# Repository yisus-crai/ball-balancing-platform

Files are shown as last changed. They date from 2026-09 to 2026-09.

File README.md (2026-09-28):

# 2-DOF Ball-Balancing Platform

<p align="center">
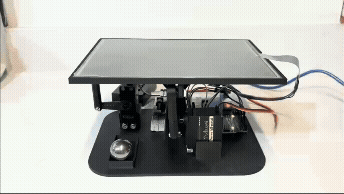
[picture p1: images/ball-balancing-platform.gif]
Ball-balancing demo
  
</p>

## About
A two-degree-of-freedom ball-balancing platform designed, built, and programmed as a personal engineering project.

The platform uses a resistive touchscreen to measure the ball position and two servomotors to tilt the surface. Two independent closed-loop PID controllers stabilize the ball near the center of the platform. 

## Project Goals

- Apply classical control concepts to a physical system.
- Design and manufacture the mechanical structure.
- Implement real-time position measurement and filtering.
- Develop and tune a closed-loop controller on an Arduino.
- Explore future control approaches such as state-space control and Kalman filtering.

## Hardware & Components

- Arduino UNO
- 2 × MG995 servo motors
- 8 inch 4-wire resistive touchscreen
- External 5 V power supply for the servo motors
- Custom 2-DOF mechanical platform (designed via CAD + 3D-printed)
- 25 mm diameter stainless-steel ball

## Design

The platform was designed as a two-degree-of-freedom mechanism capable of tilting independently around the X and Y axes.

The mechanical structure consists of:

- A fixed base.
- A moving platform that supports the resistive touchscreen.
- Two MG995 servomotors, one for each axis.
- Mechanical linkages that convert servo rotation into platform tilt.
- 3D-Printed structural components.
- A ball used as the controlled object.

All structural components were designed in CAD using Autodesk Fusion and manufactured by 3D printing in PLA. The design was iterated to achieve adequate rigidity, servo clearance, and a suitable range of platform motion. 

<p align="center">
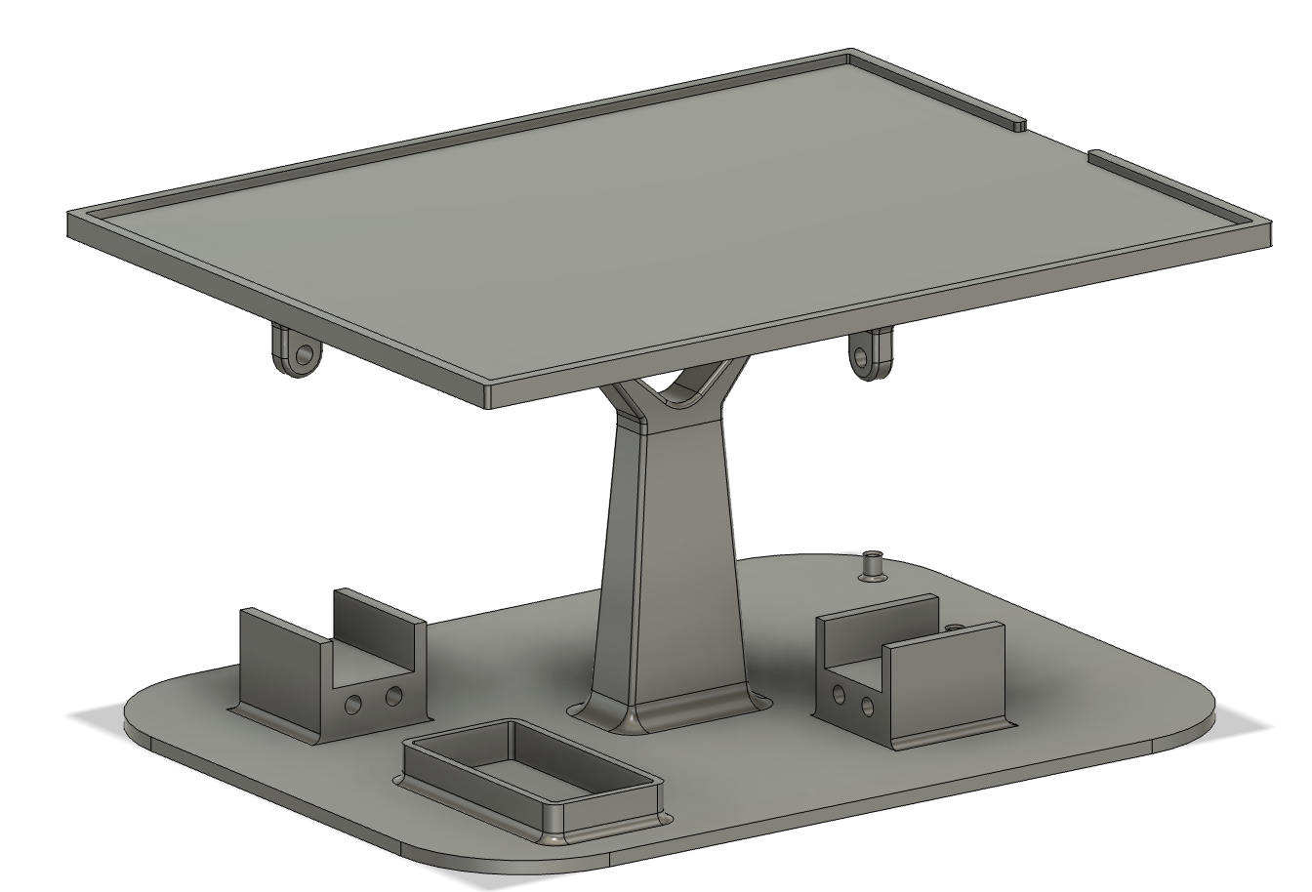
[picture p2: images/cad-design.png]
cad design assembled
  
</p>

The final assembly uses bolts and nuts to join the printed parts, servomotors and base structure. The touchscreen is fitted into the tilting platform with minimal clearance to prevent displacement, avoiding the use of bolts that could apply unwanted stress to the touchscreen.

The platform tilt was limited to approximately ±10° on each axis. This constraint reduces excessive ball acceleration, keeps the ball in contact with the touchscreen, and prevents mechanical interference.

##  Software Architecture

The Arduino firmware is organized around a repeated sensing, filtering, control, and actuation loop.

1. **Position measurement**  
   The Arduino reads the X and Y coordinates from a 4-wire resistive touchscreen.

2. **Signal filtering**  
   A median filter rejects outliers from the touchscreen measurements. An Exponential Moving Average (EMA) then smooths the remaining noise.

3. **Control computation**  
   Independent PID controllers calculate the required correction for the X and Y axes. Each controller stores its own gains, filtered position, previous error, integral state, derivative state, and output limits.

4. **Actuation**  
   The controller outputs are converted into servo commands relative to the mechanical neutral position.

5. **Safety handling**  
   If the ball is not detected for a defined period, both servos return to the neutral position and the controller states are reset.

Main Code Components:

- `AxisControl`: Stores the state and parameters associated with one control axis.
- `median()`: Calculates the median of recent touchscreen measurements.
- `ema()`: Applies the exponential moving average filter.
- `PID()`: Calculates the control output for an axis.
- `restartAxis()`: Resets controller states after ball detection is lost.

## Troubleshooting

Several practical issues arose during development and were addressed as follows:

- **Excessive serial output slowed down the control loop.**  
  Frequent `Serial.print()` calls introduced delays and degraded the controller performance.  
  - **Solution:** Reduce or disable serial output during normal operation. Use `Serial.print()` only for debugging.

- **Inadequate servo power supply reduced actuator performance.**  
  Powering the servos from the Arduino 5 V pin resulted in slow and unreliable motion.  
  - **Solution:** Power the servos from a suitable external 5 V supply and connect its ground to the Arduino GND.

- **Derivative kick occurred when the ball was first detected.**  
  The derivative term produced a large output because the previous error was not initialized.  
  - **Solution:** Initialize the controller state after obtaining the first valid position measurements, then enable derivative control.

- **Filtering introduced a trade-off between noise reduction and response delay.**  
  Excessive filtering made the position estimate smoother but delayed the control action.  
  - **Solution:** Tune the median-filter window, EMA coefficient, and sampling interval to balance noise rejection and responsiveness.

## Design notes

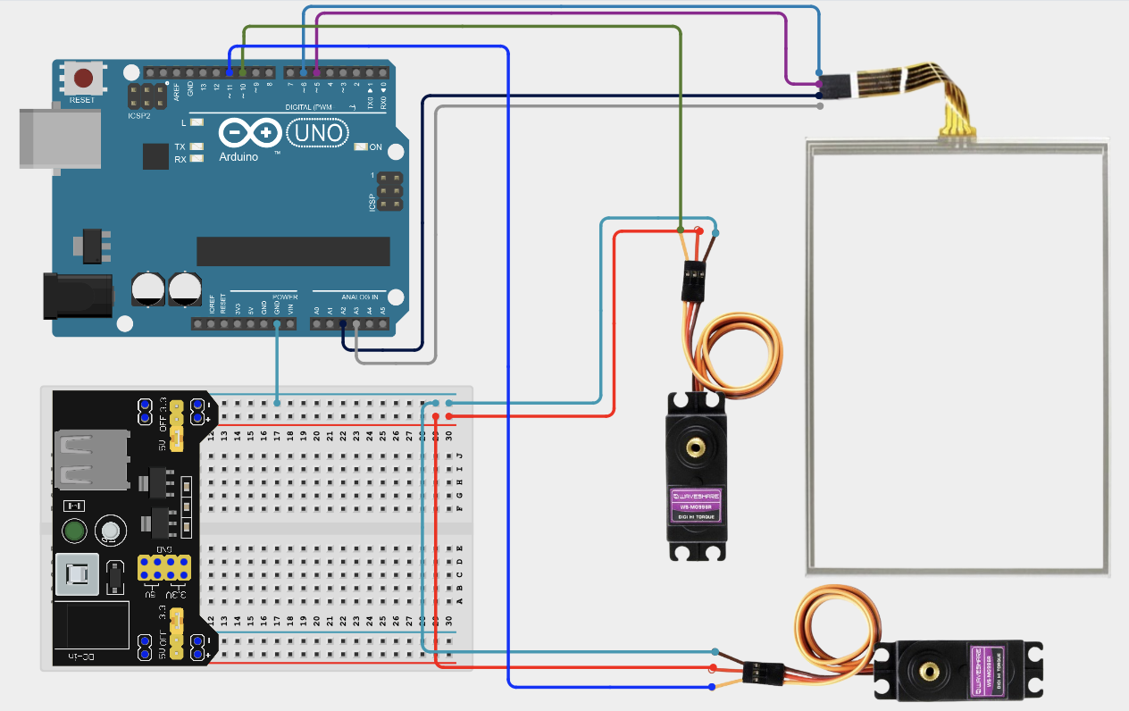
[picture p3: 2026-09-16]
electronics/ball-balancing electronics scheme.png

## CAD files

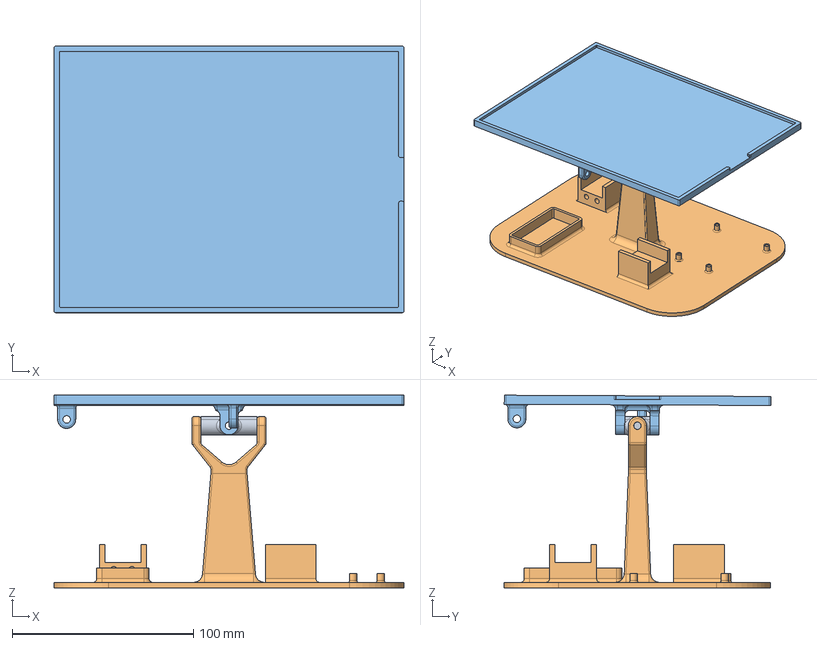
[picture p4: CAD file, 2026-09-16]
cadfiles/ball-ballancing platform assembled.step
193.0 x 147.1 x 106.2 mm

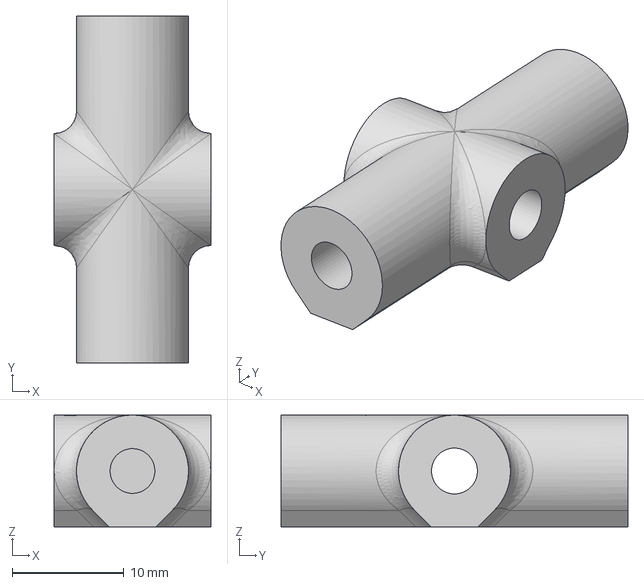
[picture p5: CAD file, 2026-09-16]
cadfiles/cardan link.step
14.0 x 31.0 x 10.00 mm

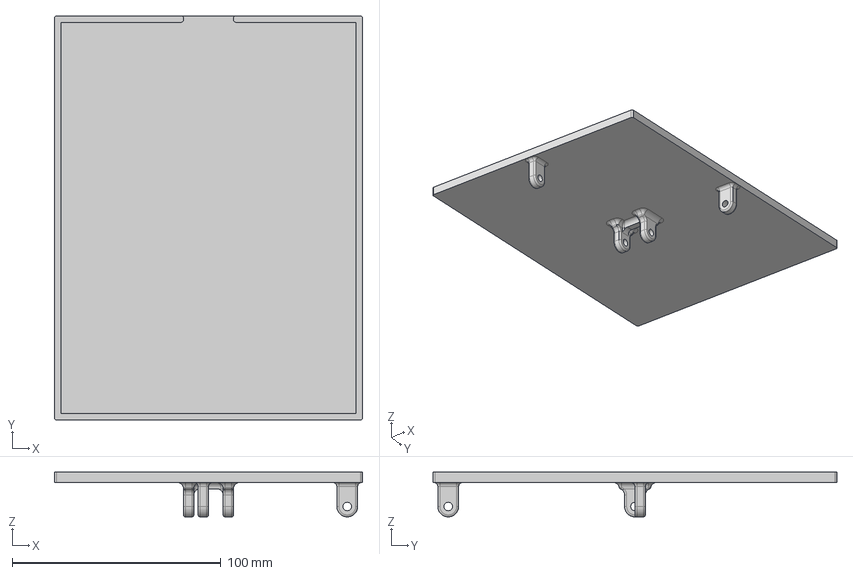
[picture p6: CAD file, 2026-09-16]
cadfiles/platform.step
147.6 x 193.6 x 21.5 mm

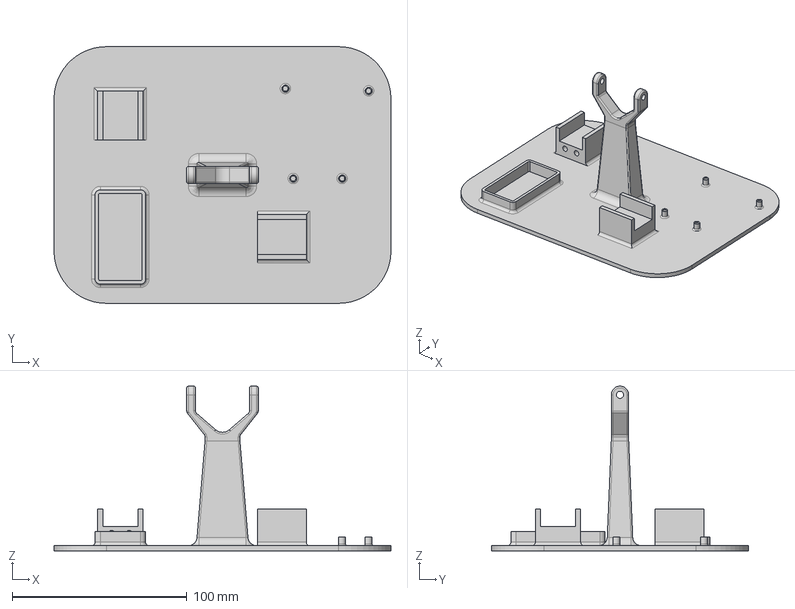
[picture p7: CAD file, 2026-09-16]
cadfiles/base.step
193.0 x 147.0 x 94.4 mm

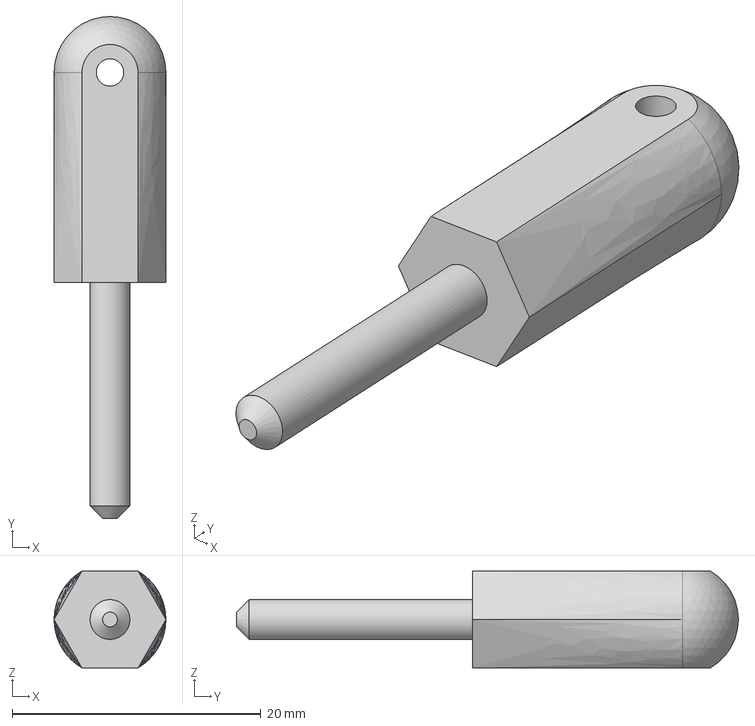
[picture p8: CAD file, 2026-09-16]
cadfiles/connecting rod.step
9.01 x 40.4 x 7.80 mm

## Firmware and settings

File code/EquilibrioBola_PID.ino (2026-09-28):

// Automatic 2-DOF ball-balancing platform
// PID CONTROL

#include <stdint.h>
#include "TouchScreen.h"
#include <Servo.h>

// Pines de control de la pantalla táctil resistiva
#define YP A2
#define XM A3
#define YM 6
#define XP 5

// Valores de calibración de posición de la pantalla táctil
const int TS_MINX = 74;
const int TS_MAXX = 969;
const int TS_MINY = 104;
const int TS_MAXY = 934;

// Pines de servomotores
#define XAxis 11
#define YAxis 10

// Variables de filtrado
const int maxData = 5;
const float alpha = 0.8f;

//Estructura de datos de errores (Algoritmo PID)
struct ErrorState {
  float previous;
  float actual;
};

//Estructura de datos de ganancias de controlador PID
struct PIDConstants {
  float p;  // Ganancia proporcional
  float i;  // Ganancia integral
  float d;  // Ganancia derivativa
};

//Estructura de datos de valores límites
struct limitValues {
  float min;
  float max;
};

// Estructura de datos de control por eje
struct AxisControl {
  // Filtrado medida (mediana + EMA)
  int medianArray[maxData]; //Array para obtener la mediana de medidas
  float previousPosition;
  float filteredPosition;

  // Algoritmo control PID
  ErrorState error;
  PIDConstants K;
  const float reference;
  float integral;
  float derivative;
  bool pidInitialized;
  limitValues outputLimit;
  float debug;
};

// Función para cálculo de mediana de un array
int median(int a[maxData]) {
  int b[maxData];
  memcpy(b, a, sizeof(b));  // copia, para no tocar el buffer original
  for (int i = 1; i < maxData; i++) {   // ordenación por inserción
    int key = b[i];
    int j = i - 1;
    while (j >= 0 && b[j] > key) {
      b[j + 1] = b[j];
      j--;
    }
    b[j + 1] = key;
  }
  return b[maxData/2];  // valor central
}

// Función para cálculo de EMA
float ema(AxisControl axis){
  return alpha * median(axis.medianArray) + (1-alpha) * axis.previousPosition;
}

// Algoritmo de control PID
float PID(AxisControl& axis, float calcTime){
  axis.error.actual = axis.reference - axis.filteredPosition;

  // Control proporcional
  float proportional = axis.K.p * axis.error.actual;

  // Control integral
  axis.integral += (axis.error.actual + axis.error.previous) / 2.0f * calcTime;
  float integral = constrain(axis.K.i * axis.integral, -30, 30); //Anti-windup

  // Control derivativo
  float derivative = 0;
  if (axis.pidInitialized) { // Eliminar derivative kick
    axis.derivative = axis.K.d * (axis.error.actual - axis.error.previous) / calcTime;
  }
  axis.pidInitialized = true;

  // Ley de control
  float output = proportional + integral + axis.derivative;

  // Actualización del error
  axis.debug = axis.error.previous;
  axis.error.previous = axis.error.actual;

  // Enviar señal de control saturada a planta
  return constrain(output,axis.outputLimit.min, axis.outputLimit.max);
}

// Función de reinicio de variables
void restartAxis(AxisControl& axis){
  axis.integral = 0;
  axis.error.previous = 0;
  axis.error.actual = 0;
  axis.pidInitialized = false;
}

// Inicialización de la pantalla táctil
TouchScreen ts = TouchScreen(XP, YP, XM, YM, 299);  // Resistencia en eje X medida con multímetro

// Inicialización de servomotores
Servo servoX;
Servo servoY;

// Inicialización de ejes
AxisControl controlX = {};
AxisControl controlY = {};


void setup() {
  // Asignación de pines de servomotores
  servoX.attach(XAxis);
  servoY.attach(YAxis);
  ts.pressureThreshhold = 5;

  // Valores de constantes del control del eje X
  controlX.K.p = 0.2;
  controlX.K.i = 0.05;
  controlX.K.d = 0.1;
  controlX.outputLimit.min = -50;
  controlX.outputLimit.max = 50;

  // Valores de constantes del control del eje Y
  controlY.K.p = 0.15;
  controlY.K.i = 0.05;
  controlY.K.d = 0.1;
  controlY.outputLimit.min = -40;
  controlY.outputLimit.max = 40;

  //Posición inicial servomotores
  servoX.write(90);
  servoY.write(90);
}


void loop() {
  // Inicio de tiempo
  unsigned long startTime = millis();
  unsigned long lastRead = 0;
  unsigned long lastDetection = 0;
  int numData = 0;
  
  // Recopilación de medidas de pantalla resistiva
  while (numData < maxData){
    // Leer solo cada 10 ms
    if (millis() - lastRead >= 10) {
      lastRead = millis();
      // Lectura de pantalla resistiva
      TSPoint p = ts.getPoint();  

      // Si existe detección, se registra la posición
      if (p.z > ts.pressureThreshhold) {
        lastDetection = millis();
        //Calibración de posición
        int x = map(p.x, TS_MINX, TS_MAXX, -85, 85);
        int y = map(p.y, TS_MINY, TS_MAXY, 64, -64);

        //Filtrado de coordenadas
        controlX.medianArray[numData] = x;
        controlY.medianArray[numData] = y;
        numData++;
      }
    }
    //Salir del bucle while y volver a posición inicial tras tiempo sin detección
    if (millis() - lastDetection > 500){
      break;
    }
  }

  //Medida correcta - Inicio algoritmo PID
  if (numData == maxData){
  //Filtrado mediana + EMA 
  controlX.filteredPosition = ema(controlX);
  controlY.filteredPosition = ema(controlY);
  
  //Actualización valores previos
  controlX.previousPosition = controlX.filteredPosition;
  controlY.previousPosition = controlY.filteredPosition;

  //Control PID
  float calcTime = (millis() - startTime) / 1000.0f;
  float outputX = PID(controlX, calcTime);
  float outputY = PID(controlY, calcTime);

  //Enviar señal de control a la planta
  servoX.write(90 - outputX);
  servoY.write(90 + outputY);
  }
  
  //Tiempo de espera agotado - Reinicio de sistema
  else {
    //Posición inicial servomotores
    servoX.write(90);
    servoY.write(90);

    //Reinicio errores e integral de ejes
    restartAxis(controlX);
    restartAxis(controlY);
  }
}

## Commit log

2026-09-28 Component list and electronics assembly scheme
2026-09-28 All cad files
